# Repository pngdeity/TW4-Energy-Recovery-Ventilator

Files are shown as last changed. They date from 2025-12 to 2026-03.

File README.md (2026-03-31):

<p align="center">
  OpenERV Logo
</p>

# OpenERV TW4 and WM12






OpenERV is a 87%+ efficiency DIY **Energy Recovery Ventilator (ERV)** system designed to provide fresh outdoor air while recovering heat and moisture from the exhaust stream. This repository contains the complete firmware, mechanical designs, and documentation for the **TW4** (Through-Wall) and **WM12** (Window-Mounted) models.

## Key Features
- **High Efficiency**: 87%+ heat recovery efficiency at 60 CFM.
- **Precision Control**: Integrated PID loops for automated pressure regulation using Sensirion SDP810 sensors.
- **IoT Enabled**: Built-in WiFi and MQTT support for remote monitoring and automation.

- **UDP Synchronization**: Leader/Follower UDP synchronization for multi-module installations.

## Project Structure

- **`firmware/`**: MicroPython source code for the Raspberry Pi Pico W.
  - `common/`: Modular core engine, drivers, and safety state machine.
  - `tw4/`, `wm12/`: Model-specific entry points.
- **`design/`**: Mechanical and electrical design assets.
  - `parts/`: STL and STEP files for all printable components.
  - `schematics/`: PCB designs and wiring diagrams.
- **`docs/`**: Manuals, assembly guides, and technical specifications.
- **`research/`**: Historical CAD iterations and experimental validation data.
- **`scripts/`**: Automation utilities for manufacturing analysis and BOM extraction.

## Installation (Flashable Firmware)

The fastest way to deploy OpenERV is to use our pre-compiled firmware images:

1. Download the latest **`.uf2`** binary for your model from the [GitHub Releases](https://github.com/pngdeity/TW4-Energy-Recovery-Ventilator/releases) page.
2. Hold the **BOOTSEL** button on your Raspberry Pi Pico W and connect it to your computer via USB.
3. Drag and drop the `.uf2` file into the `RPI-RP2` drive. The unit will automatically reboot into the OpenERV engine.

## Configuration

After flashing, you must configure your local environment:
1. Locate the relevant template in `firmware/config_templates/`.
2. Copy it to the root of your Pico's filesystem as `persistent_vars.json`.
3. Edit the file to include your WiFi credentials, model ID, and optional Adafruit IO keys.

## Documentation & Roadmap

Manuals and assembly instructions:
- [DIY Manufacturing Guide](./docs/Document%20to%20aid%20DIY%20manufacturing%20of%20the%20OpenERV%20TW4%20and%20WM12.md)
- [TW4 Manual](./docs/TW4%20manual%20-%20OpenERV.md)
- [WM12 Manual](./docs/OpenERV%20WM12%20manual.md)
- [v1.0 Roadmap](./ROADMAP.md)

## Original Project & Attribution

This project is a formalized fork of the OpenERV system originally developed by **Anthony Douglas**.
- **Original Website**: [openerv.ca](https://www.openerv.ca)
- **Licensing**: This project is licensed under **CC BY-NC-SA 4.0**. See [LICENSE](LICENSE) for details.

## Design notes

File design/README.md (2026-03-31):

# OpenERV Hardware Design

This directory contains all the mechanical and electrical design files for the OpenERV TW4 and WM12 units.

## Directory Structure

- **`parts/`**: 3D design files (STL for printing, STEP for CAD modeling).
  - **`common/`**: Parts shared by both TW4 and WM12 models (covers, plates, noise splitters).
  - **`tw4/`**: Parts unique to the TW4 model (e.g., flow straighteners).
  - **`wm12/`**: Parts unique to the WM12 model (e.g., window adapters).
- **`schematics/`**: Electrical schematics, PCB layouts, and sensor pinouts.
  - **`source/`**: Raw EasyEDA JSON source files.

## Bill of Materials (BOM)

Bills of Materials are provided in the [OSHWA](https://www.oshwa.org/) recommended CSV format:
- **`BOM_TW4.csv`**: Parts list for a single TW4 module.
- **`BOM_WM12.csv`**: Parts list for a complete WM12 window-mounted unit (includes 2x modules and adapter hardware).

These files include component names, quantities, technical descriptions, and suggested sourcing information (e.g., LCSC/DigiKey part numbers where applicable).

## Manufacturing

### Automated Manufacturing Reports
This repository uses **PrusaSlicer CLI** in a GitHub Action to automatically audit every 3D model change. On every push to the `main` branch, a report is generated containing:
- **Print Time Estimates**: Calculated using the project's manufacturing profile.
- **Material Usage**: Estimated weight in grams.
- **Physical Dimensions**: Precise bounding box measurements.

The latest report can be found in the `design/` directory as **`MANUFACTURING_REPORT.csv`**.

### 3D Printing Specifications
Material and slicer requirements are provided in **`print_specs.json`** files within each sub-directory. These files use a schema to define:
- **Recommended Materials**: (e.g., MPLA for high thermal resistance).
- **Infill Settings**: Specific densities and patterns (e.g., 100% infill for mechanical regions).
- **Layer Details**: Wall counts and layer heights required for structural integrity.

For detailed assembly and manufacturing instructions, please refer to the documentation in the root `docs/` directory:
- [DIY Manufacturing Guide](../docs/Document%20to%20aid%20DIY%20manufacturing%20of%20the%20OpenERV%20TW4%20and%20WM12.md)
- [TW4 Manual](../docs/TW4%20manual%20-%20OpenERV.md)
- [WM12 Manual](../docs/OpenERV%20WM12%20manual.md)

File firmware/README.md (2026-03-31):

# OpenERV Firmware

This directory contains the MicroPython firmware for the OpenERV TW4 and WM12 units. The firmware has been refactored into a modular, object-oriented architecture to maximize code reuse and reliability across different hardware models.

## Software Architecture

The firmware follows a **Core-Wrapper** pattern. The heavy lifting is handled by a shared core library, while model-specific directories contain minimal configuration and entry logic.

### 1. Model Entry Points (`/tw4` and `/wm12`)
These directories contain the `main.py` files that serve as the entry point for the Raspberry Pi Pico W.
- **`main.py`**: A "thin wrapper" that defines model-specific constants (like pressure gains and I/O pins) and instantiates the `OpenERVCore`.
- **`persistent_vars.json`**: (User-created) Local configuration file containing WiFi credentials and device-specific settings.

### 2. Common Library (`/common`)
This directory contains the engine of the project. By centralizing this logic, we ensure that improvements to the PID loop or networking stability benefit all models simultaneously.
- **`core_logic.py`**: Contains the `OpenERVCore` class. This is the main state machine that orchestrates sensor reading, PID calculation, fan control, and network synchronization (Leader/Follower).
- **`sdp810.py`**: A class-based driver for the Sensirion SDP810 differential pressure sensor with built-in error handling.
- **`fan_manager.py`**: Manages fan pairs and implements the coordinated ramp-down logic required for efficient energy recovery.
- **`network_manager.py`**: Handles WiFi station connections and Access Point (AP) mode.
- **`simple_pid/`, `umqtt/`, `uping.py`**: Standardized third-party libraries for PID control, MQTT communication, and network diagnostics.

### 3. Configuration Templates (`/config_templates`)
Contains example `persistent_vars.json` files for each model. To configure a new device:
1. Copy the relevant template to the root of your Pico.
2. Rename it to `persistent_vars.json`.
3. Update it with your WiFi and Adafruit IO credentials.

### 4. Experimental Scripts (`/experimental`)
Diagnostic and characterization tools used for hardware validation and efficiency measurements. See the [Experimental README](./experimental/README.md) (if available) for more details.

## Control Logic Flow

1. **Initialization**: The device loads configuration, initializes the I2C sensor, and sets up PWM for the fans.
2. **Connectivity**: The unit attempts to connect to WiFi. If configured as a **Leader**, it optionally connects to MQTT for telemetry. If a connection fails, it may fall back to **Access Point** mode.
3. **Synchronization**:
   - **Leaders** broadcast their internal clock and power settings via UDP.
   - **Followers** listen for these UDP packets to synchronize their cycles with the leader.
4. **The Loop**:
   - **Ingress Phase**: The unit runs a PID loop to maintain the target pressure for incoming air.
   - **Egress Phase**: The unit reverses the cycle, running a PID loop for outgoing air.
   - **Ramping**: The `FanManager` ensures that fans don't snap between speeds, protecting the hardware and reducing noise.

## Development Guidelines

- **Stay Modular**: Do not add hardware-specific logic to `core_logic.py`. Instead, add a configuration parameter to the `OpenERVCore` constructor.
- **Error Resilience**: Always use `try/except` blocks when communicating with I2C sensors or network sockets to prevent the device from hanging.
- **WDT**: The Watchdog Timer is enabled by default. Ensure that any long-running operations (like network handshakes) "feed" the watchdog to avoid unintended resets.

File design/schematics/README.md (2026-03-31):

# OpenERV Schematics and PCB Design

This directory contains the electrical design files for the OpenERV systems.

## Contents

- **`pcb_schematic_v2.png`**: Current schematic for the TW4/WM12 main board.
- **`pcb_schematic_v1.pdf`**: Previous version or alternative view of the schematic.
- **`sensor_sdp810_pinout.png`**: Pinout reference for the Sensirion SDP810 differential pressure sensor.
- **`source/`**: Contains the raw EDA source files.
  - `1-Schematic_TW4 Main board2.json`: EasyEDA schematic source.
  - `1-PCB_PCB_TW4 Main board2.json`: EasyEDA PCB layout source.

## Using the Source Files

The source files in the `source/` directory are in **EasyEDA (Standard Edition)** format. To view or modify them:

1. Go to [EasyEDA](https://easyeda.com/).
2. Log in and open the Editor.
3. Use **File -> Open -> EasyEDA...** and upload the `.json` files.
4. You can then export Gerbers, BOMs, and Pick-and-Place files directly from the editor for manufacturing.

## Component Sourcing

Key components like the Raspberry Pi Pico W and the SDP810 sensor should be sourced from reputable suppliers (e.g., DigiKey, Mouser) to ensure reliability. Refer to the project manuals in the `docs/` folder for detailed Bills of Materials (BOM).

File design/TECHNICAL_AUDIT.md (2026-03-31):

# Technical Audit: OpenERV Design Assets

This document details the findings of a technical audit performed on the mechanical and electrical design files within the `design/` directory.

## 1. Summary of STL Analysis

All STL files were analyzed using `admesh` for geometric integrity and physical dimensions.

| Part Name | Status | Parts | Volume (mm³) | Bounding Box (mm) | Issues Found |
| :--- | :--- | :--- | :--- | :--- | :--- |
| `combi_hood.stl` | Healthy | 1 | 158,890 | 166.6 x 175.6 x 151.6 | None |
| `fiberglass_grid.stl` | Healthy | 1 | 11,696 | 195.6 x 166.6 x 3.0 | None |
| `filter_clamp.stl` | Healthy | 1 | 17,450 | 208.5 x 101.5 x 33.5 | None |
| `filter_seat.stl` | Healthy | 1 | 80,682 | 214.9 x 182.0 x 20.0 | None |
| `hat_seat.stl` | Healthy | 1 | 34,282 | 173.0 x 177.3 x 12.0 | None |
| `indoor_plate.stl` | Healthy | 1 | 161,253 | 187.7 x 219.1 x 14.5 | Tight fit for 220mm beds. |
| `interior_cover.stl` | Healthy (Fixed) | 1 | 180,584 | 200.0 x 220.8 x 75.1 | Normals repaired. |
| `noise_splitter.stl` | Healthy | 2 | 669,905 | 184.0 x 166.9 x 218.8 | Multi-body part (intentional?). |
| `outdoor_cover.stl` | Healthy (Fixed) | 1 | 394,679 | 223.0 x 230.8 x 146.8 | Normals repaired. Requires 250mm+ bed. |
| `outdoor_plate.stl` | Healthy (Fixed) | 1 | 462,341 | 215.0 x 220.0 x 18.0 | Normals repaired. |
| `pipe_extension.stl` | Healthy | 1 | 31,915 | 111.6 x 111.6 x 33.0 | None |
| `pot_mount.stl` | Healthy | 1 | 3,914 | 23.0 x 23.0 x 29.2 | None |
| `pot.stl` | Healthy | 1 | 2,712 | 24.0 x 16.4 x 23.8 | None |
| `regen.stl` | Healthy | 1 | 3,096,175| 148.5 x 148.8 x 180.0 | High volume print. |
| `std_filter_plate.stl`| Healthy | 1 | 66,482 | 209.3 x 182.0 x 20.0 | None |
| `clamp_v2.stl` | Healthy | 1 | 69,363 | 159.0 x 159.0 x 10.0 | None |
| `flow_straightener.stl`| Healthy | 1 | 59,999 | 120.4 x 120.4 x 19.0 | None |

## 2. Integrity Issues & Proposed Changes

### A. Surface Normal Correction
Several files exhibit "Flipped Normals" or "Backwards Edges." While most modern slicers (Cura, PrusaSlicer) can auto-repair these on import, they can cause issues with professional CNC or injection molding software.
- **Proposed Change**: Re-export `interior_cover.stl`, `outdoor_cover.stl`, and `outdoor_plate.stl` from the source CAD with unified surface normals to ensure manifold integrity.

### B. Printer Bed Compatibility
- **`outdoor_cover.stl`**: At 223mm x 230mm, this file exceeds the standard 220mm (Ender 3 class) print bed.
- **`interior_cover.stl`**: At 220.8mm, it may fail on printers with strict software endstops.
- **Proposed Change**: Consider a minor design revision to the `outdoor_cover` to bring the largest dimension under 215mm, or explicitly mark this part as "Large Format Only" in the filename.

### C. Multi-Body Parts
- **`noise_splitter.stl`**: Contains 2 distinct shells. This can sometimes cause slicers to treat them as overlapping solids, leading to over-extrusion at the boundary.
- **Proposed Change**: Merge shells into a single manifold boolean object before re-exporting.

## 3. STEP File Verification
The STEP files (`rev_11_tw4_v35.step`, etc.) are in standard ISO-10303-21 format.
- **Observation**: The filenames are inconsistent with the STL counterparts.
- **Proposed Change**: Rename STEP files to match the part names used in the `stls/` directory for better cross-referencing.

## 4. Electrical Schematics
The EasyEDA source files are current but use proprietary JSON schema.
- **Proposed Change**: In the next design cycle, include an **IPC-2581** or **ODB++** export in the `schematics/source` directory to provide a software-agnostic manufacturing exchange format.

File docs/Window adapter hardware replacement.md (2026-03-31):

# WM12 Technical Specification: Hardware Replacement

This document lists the standard hardware components required for the WM12 window adapter.

## Mechanical Components

### Clamps
- **Type**: Key-type hose clamps.
- **Diameter**: 6 inches (approx. 152 mm).

### Fasteners
- **Screws**: 3/4 inch, Number 2 Robertson (Square Drive, Green).

### Brackets
- **Type**: Standard 1.5-inch metal brackets (generic hardware store stock).

### Structural Timber
- **Dimension**: 2x2 nominal (actual approx. 1.5" x 1.5" or 38mm x 38mm).

### Sealing Medium
- **Material**: Polypropylene (PP) foam plate.
- **Source**: Commonly used as industrial packaging material.

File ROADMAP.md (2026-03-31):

# OpenERV v1.0 Roadmap

This roadmap outlines the critical tasks and features required to reach a Version 1.0 milestone.

## 1. Hardware Completeness (Mechanical)
- [ ] **Release Mandrel CAD**: Publish the design files for the Heat Exchanger Hat forming mandrel.
- [ ] **Validated Assemblies**: Confirm that all renamed STEP files correctly resolve in standard CAD software (KiCad/FreeCAD).
- [ ] **Assembly Video/Guide**: Create a visual assembly guide to supplement the Markdown documentation.

## 2. Firmware Functionality & Safety
- [ ] **Automated Defrost Cycle**: Implement logic to detect frost accumulation (via pressure drop) and trigger a temporary exhaust-only purge.
- [ ] **PID Auto-Tuning**: Provide model-specific PID constants for TW4 and WM12 based on physical volume characterization.
- [ ] **Watchdog Hardening**: Refine WDT timeouts for critical networking handshakes to prevent false-positive reboots.

## 3. User Experience (UX)
- [ ] **IoT Provisioning (V1.0)**: Mature the Captive Portal to include a WiFi scanner (showing available SSIDs).
- [ ] **Persistent Variables Validation**: Add schema validation for `persistent_vars.json` to prevent boot loops from malformed JSON.
- [ ] **Home Assistant Discovery**: Implement MQTT discovery for smart home integration.

## 4. Electronics & Manufacturing
- [ ] **KiCad Migration**: Transition the main PCB from EasyEDA to KiCad for full open-source toolchain support.
- [ ] **Production Gerbers**: Include a verified set of Gerber files in each release.
- [ ] BOM Finalization: Finalize LCSC part mappings for all components to support automated PCBA services.

## 5. Community & Standards
- [ ] **OKH Certification**: Submit the project for official Open Source Hardware Association (OSHWA) certification.
- [ ] **Contributor Guide**: Expand `CONTRIBUTING.md` with technical environment setup instructions.

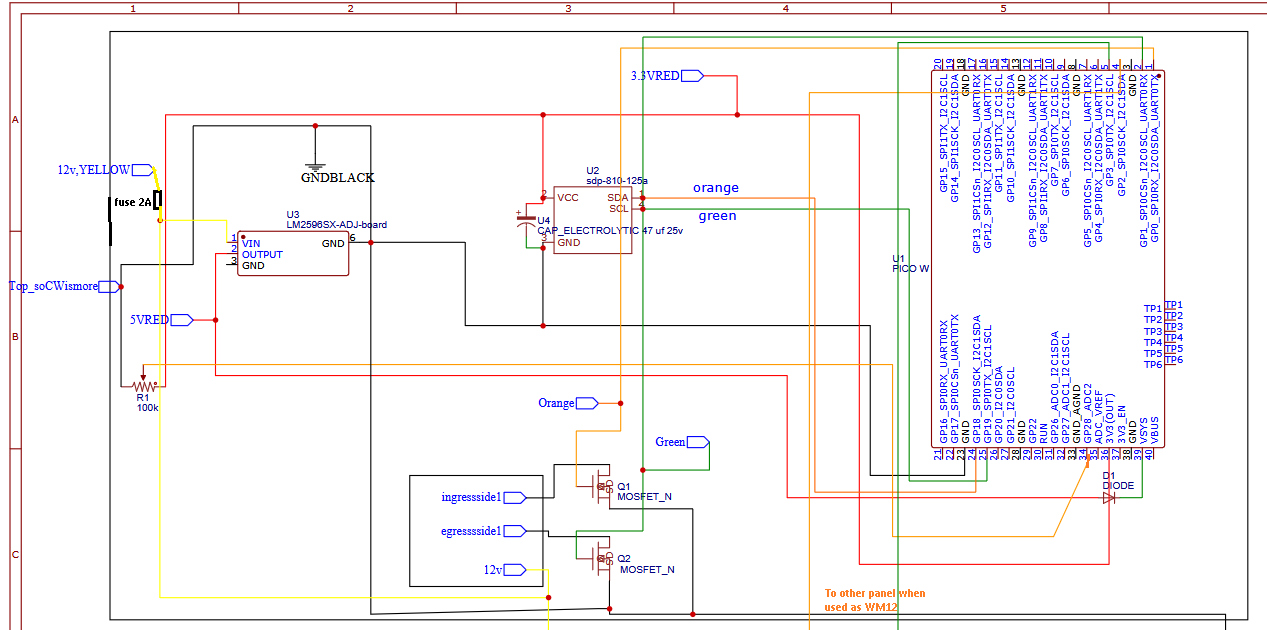
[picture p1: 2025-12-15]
design/schematics/pcb_schematic_v2.png

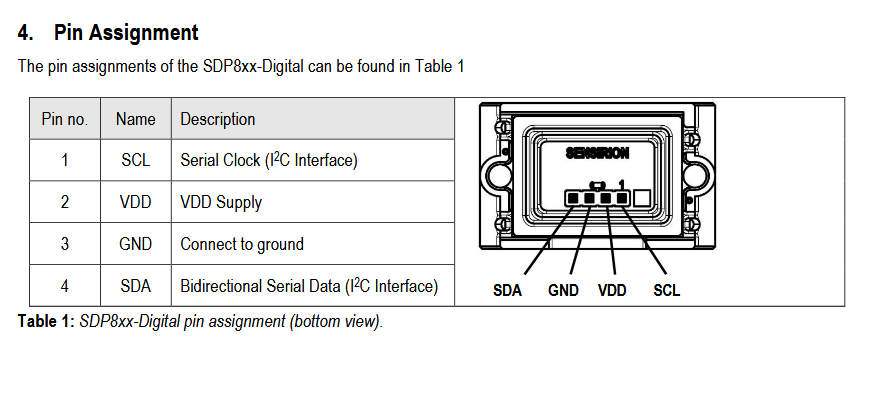
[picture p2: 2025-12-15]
design/schematics/sensor_sdp810_pinout.png

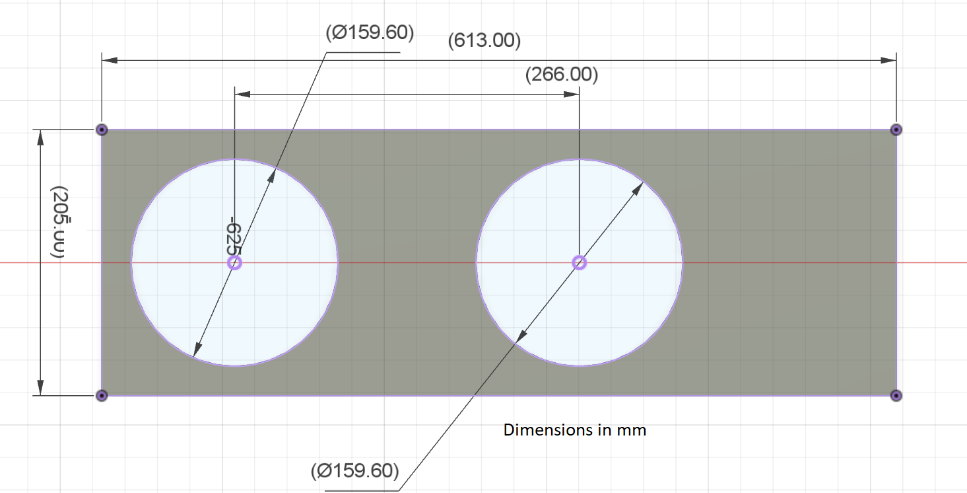
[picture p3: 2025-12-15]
wm12/WM12/v2foamplatewindowadapterforwm12.png

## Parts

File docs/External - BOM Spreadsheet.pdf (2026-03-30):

Input cells are in blue, the most important output cells are in red, you need to save a copy before you can edit. The methodology is similar to that used here https://www.caee.utexas.edu/prof/Novoselac/classes/ARE389H/Handouts/Old_Projects/ERV%20Report.pdf, which assumes a thermal wheel. The physics for the ductless (both regenerative) type are mostly the same, but not for the recouperative, they have issues at low temperatures due to frost. units | All dollars are Canadian dollars units Flow rate, CFM: | 15 CFM | Actual amount of fresh air, remember this is usually for a *pair* of units cost of electricity, dollars per kWh | 0.16 kWh | factoring in lifespan of unit to running cost. This means the average time before the initial cost of the unit has been expended upon maintenance. For conventional units, this will depend on if you can get replacement parts, or if the whole thing becomes trash when e.g. the fan wears out.
flow rate, liters per second: | 7.075 liters per second | cost per cubic meter of natural gas, dollars | 1.3 CAD/m^3 | notes
electrical power consumed by device when at that flow, Watts. | 7 | Watts | cost per kWh of natural gas derived heat energy | 0.1336211327 CAD/kWh | lifespan | 40 years Months on per year | 8 | Months | This figure is not strictly necessary, the calculations could be done with the heating degree days per year, however it is used to calculate some intermediate figures. assumed purchase price for a pair of modules | 1000 CAD | Initial cost, including tax and shipping etc. for heat recovery aspect | 1110 CAD
electrical Energy consumed, per year, kWh: | 40.88 kWh | tax/duty | 15 | Percent | Spare parts and electricity per year etc along the way | 16.5408 CAD/year
liters of air per day provided, fresh air | 611280 liters per day | shipping | 60 | CAD | Gross cost of ownership/operation (no interest, comparative value only) per year | 44.2908 CAD/year energy to heat the air for the year without any heat recovery, kWh, sensible only | 953.5968 kWh | installation | 0 | CAD | Gross return on investment (assuming natural gas heat) | 170.7848207 CAD/year efficiency of heat recovery, sensible | 0.85 Unitless ratio | rebates/tax credits etc., some governments give these | 0 CAD | Net return on investment, per year | 126.4940207 CAD/year heat energy directly saved by device, sensible, per year | 810.55728 kWh | value of the fan, without heat recovery (you need a fan anyway most of the time, reduce this figure for retrofit if you are replacing an existing but functional fresh air supply system with no heat recovery) 100 CAD | Net Ownership/operating cost over total lifespan | 1771.632 CAD
heat capacity of air, volumetric, joules per degree per liter | 1.2 J/DegC-Liter | Total cost including fan aspect | 1210 | CAD Marginal cost of heat recovery aspect of the machine (the house needs a fan anyway) | 1110
heating-degree-days per year: | 4,680 degree-days per year https://portfoliomanager.energystar.gov/pm/degreeDaysCalculator , https://www.degreedays.net System running cost, per year, including electricity | 16.5408 CAD | Total cost of energy saved over life span,natural gas: | 6831.39283 CAD Maintenance cost, per year, worn parts etc. (estimate, includes labor) | 10 dollars | gross dollars saved on heating, assuming natural gas heat | 170.7848207 CAD | Total cost of energy saved over life span, electric: | 8180.014873 CAD | energy saved, kWh 51125.09295
latent heat recovery efficiency, seasonal average (Toronto) | 0.8 unitless ratio | Change this if using coated vs uncoated exchagners! Makes a big diff. gross dollars saved on heating, assuming electric heat | 204.5003718 CAD | ratio of ownership per year cost to energy saved per year, natural gas | 0.259336865 Ratio, lower is better kWh per dollar expended 28.8576256 Fraction of total heat that is is expected to be present as latent heat | 0.38
0.4 is about right for toronto, I checked the weather data | ratio of total ownership cost to energy savings, electric resistance heat | 0.2165805353 Ratio, lower is better
total yearly heat needed without ERV | 1538.059355 Total cubic meters of air | 223117.2
energy per cubic meter | 0.006893504198 kWh
latent heat present in air | 584.4625548
latent heat saved by device, approximate | 467.5700439 kWh | assuming seasonally, about 1/6 of total energy is latent (20%, 1/5 of sensible heat appears, in addition, as latent heat) | total savings over lifespan | 6408.382873 Total heat saved by device | 1278.127324 kWh | These figures don't include running costs and lifespan, use cyan colored ones for more accuracy. | Tw4 is about 21.64 times better return on investment ratio
net averager efficiency | 0.831 Total hours of operation | 5856 | Total saved per year, natural gas heat plus savings on electric in summer on AC | 157.1542569 | CAD | with interest on savings watts thermal energy recovered, average, during operation | 218.2594474 | savings per month | 10.5411684 Embodied carbon for energy recovery ventilator: | months elapsed | 480
plastic, pla | 1.4 kg of CO2 | payoff period, years, naive (no interest), gas heat | 7.063123977 | CAD | interest rate per year | 1.03 motors | 2 kg of CO2 | Total saved per year, electric heat, not including summer | 187.9595718 | CAD | interest rate per month | 0.002466269772
electronics | 2 kg of CO2 | Total $ saved per year, electric heat plus savings on electric in summer on AC | 190.869808 | CAD | final value | $9,668.25
printing | 1 kg of CO2 | payoff period for electric heat, years, naive (no interest) | 5.815482353 | CAD
unit's embodied carbon | 6.4 kg of CO2 | Ratio of rate of return on investment, ERV to PV installation assuming natural gas heating | 1.958235292 | CAD | cost of a house | $400,000 Kg of carbon dioxide per kWh of natural gas combusted: | 0.286 Kg of CO2 per kWh of heat from natural gas | Ratio of rate of return on investment, ERV to PV installation, electric heat | 2.378351065 CAD | 41.37251896 Energy yield from one cubic meter of natural gas, kWh, with furnace at 90% efficiency: | 9.729 kWh | Carbon cost figures (doesn't factor in cooling savings) Manufacturing kg of cabon dioxide released per kWh of electricity consumed (kg carbon per kWh in the area the manufacturing is done) 0.04 | kg/kWh | cabon dioxide emission prevented per year by heating of air saved: | 231.8193821 | kg CO2 Running (kg of cabon dioxide released per kWh of electricty consumed) | 0.14 | kg/kWh | CO2 emitted by electrical consumption of device | 5.7232 | kg CO2
net carbon savings per year, kg CO2 | 226.0961821 kg CO2 Comparison with a photovoltaic array, installed | Carbon payback period of device, naive (no interest), years | 0.02830653725 | Ratio Embodied energy, kg of carbon dioxide per kW of installed panel (this is the amount which gives 1 kW of electrical energy at full sun, which is about 1.1 kw per square meter of sunlight. So several square meters of panel) 2,560 kg CO2 | Carbon payback period of an equivalent PV panel, years, if the energy from the panel is used to diplace natural gas heating energy 7.474064699 | Ratio Net kWh that 1 kW of installed panel gives, per year, in your area, kWh | 1166 kWh | https://www.energyhub.org/ontario/ Ratio of carbon payback periods: | 264.0402333 Ratio Thus, the OpenERV, at the flow rate indicated, gives the equivalent energy yield of how many kW of panel? Total energy saved, minus electrical consumption of the unit. 0.6601005832 "kW" of panel | Kg of CO2 saved per year per dollar capital investment, open erv | 0.2036902541 (kg/year)/CAD
Dollar cost of the pv system, per kW actual installed capacity (includes inverter, installation etc.) | 2200 CAD | Kg CO2 saved per year per dollar, photovoltaic | 0.0742 (kg/year)/CAD
Financial value of the OpenERV, at the same $/KWh that a photovoltaic system provides (electric heat) : 1452.221283 CAD | Ratio of Kg CO2 saved per year per dollar(ERV/PV): | 2.745151673 Ratio Dollar value of OpenERV, in equivalent PV system, natural gas heat | 2013.971943 CAD
Embodied energy of a photovoltaic array that gives the same amount of energy: | 1689.857493 kg of CO2 Carbon emission savings per year for 1kW PV array, kg of carbon | 163.24 kg CO2 PV installation running cost per kWh capacity, 1.25 percent of capital cost per year | 27.5 | https://www.powerfromsunlight.com/operational-costs-solar-panel-system/ Dollars saved per year for a 1kW PV array | 159.06 CAD
Payoff period for a 1kW PV array, naive, no interest | 13.83125864 years Payoff period, with interest | Systems of equal cost, natural gas heating

photovoltaic system ERV Units capital cost (let's assume they are the same, and scale system size) 1110 1110 CAD Interest rate, per year, percent 0.5045454545 7 7 Percent per year kW rating of PV system that costs that much

payoff rate, dollars per year | 50.96044754 80.253 40 Total heat energy saved over X years: | 157.1542569 Period to pay off, years. 10.08069767 Years to accrue energy and co2 savings (X) 9043.847283 kg monetary savings (natural gas heat maintenance and electricity cost factored in) 6286.170276 CAD 7634.792319 CAD 51125.09295 kWh Total CO2 savings over X years 2173.641174 natural gas heating assumed monetary savings (electric heat maintenance and electricity cost factored in) electric heat Equivalent value of ERV unit, cost of PV array that gives the same return
cooling physics and financial calculations | units
cooling degree days in your area | 260 degree-days | ottawa is about 260 , pheonix arazona is about 2729 https://portfoliomanager.energystar.gov/pm/degreeDaysCalculator
liters per second total watt hours of energy that could be captured at 100% efficiency latent heat energy latent efficiency sensible heat recovered, per season latent heat recovered, per season cost of electricity for heat pump without energy recovery | 7.075 L/s watts per degree (watt-days per degree days) 54.566928 kWh Coefficient of performance for heat pump 7946.64 Wh Total heat energy recovered per season 3 Electricity saved | This is a crude estimate, climate data with humidity data is needed to know more precisely. sensible efficiency

8.49 W/deg-C 52977.6 Wh 15893.28 Wh 0.88 unitless ratio 0.5 unitless ratio 46620.288 Wh 18.188976 kWh 2.91023616

| | units
Flow | 60 | cfm
efficiency, sensible | 0.7 | ratio
latent efficiency | 0.6 | ratio
electricity use | 60 | watts
capital cost | 1250 | $
expected lifespan | 8 | years
maintenance cost/yr during lifespan 0 | | $/yr
shipping | 100 | $

| | units
Flow | 85 | cfm
efficiency, sensible | 0.6 | ratio
latent efficiency | 0.6 | ratio
electricity use | 68 | watts
capital cost | 1207 | $
expected lifespan | 15 | years
maintenance cost/yr during lifespan 0 | | $/yr
shipping | 100 | $

notes: This one is recuperative, which has frost up problems in colder weather.

| | units
Flow | 30 | cfm
efficiency, sensible | 0.5 | ratio
latent efficiency | 0.2 | ratio
electricity use | 7 | watts
capital cost | 1250 | $
expected lifespan | 7 | years
maintenance cost/yr during lifespan 0 | | $/yr
shipping | 100 | $

| | units
Flow | 60 | cfm
efficiency, sensible | 0.85 | ratio
latent efficiency | 0.5 | ratio
electricity use | 13 | watts
capital cost | 650 | $
expected lifespan | 40 | years
maintenance cost/yr during lifespan 10 | | $/yr
shipping | 100 | $

parameter | value | units
Cost of heat, electric resistance | 0.165 | $/kWh
cost of heat, natural gas | 0.13 | $/kWh
tax rate on erv purhase | 0.15 | ratio
heating degree days | 4700 | degree-days per year
cooling degree days | 265 | degree-days per year
cost of a fan without erv | 0 | $

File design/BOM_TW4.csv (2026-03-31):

Index | Designator | Quantity | Name | Description | Manufacturer | Part Number | Supplier | Supplier Part Number | Footprint | Notes
1 |  | 8 | Regenerator Slices | Coated or uncoated heat exchanger slices |  |  | OpenERV |  | Custom
2 |  | 1 | Regenerator Tape | High-temp tape (Tuck Tape recommended) |  |  | Local Hardware Store |  | N/A
3 |  | 1 | Indoor Cover | 3D Printed Cover (MPLA/PLA Pro) |  |  | OpenERV |  | Custom | 250x250mm bed required
4 |  | 1 | Fiberglass Grid | 3D Printed Grid |  |  | OpenERV |  | Custom
5 |  | 1 | Potentiometer Mount | 3D Printed Mount |  |  | OpenERV |  | Custom
6 |  | 1 | Indoor Plate | 3D Printed Plate |  |  | OpenERV |  | Custom
7 |  | 1 | Noise Splitter Body | 3D Printed Main Body |  |  | OpenERV |  | Custom
8 |  | 1 | Pipe Extension | 3D Printed Inner Pipe Extension |  |  | OpenERV |  | Custom
9 |  | 1 | Hat Seat | 3D Printed Hat Seat |  |  | OpenERV |  | Custom
10 |  | 1 | Flow Straightener | 3D Printed Flow Straightener |  |  | OpenERV |  | Custom
11 |  | 1 | Fan Retention Clamp | 3D Printed Clamp |  |  | OpenERV |  | Custom
12 |  | 2 | Fan | 12V DC Fan - corners trimmed | NMB Technologies | 11925SE-12R-FT-DW | DigiKey | P12345-ND | 120mm
13 |  | 2 | Washers | 12mm washers for M3 screws |  |  | Local Hardware Store |  | M3
14 |  | 2 | M4 Bolts | 55mm long M4 bolts |  |  | Local Hardware Store |  | M4
15 |  | 2 | M4 Lock Nuts | Lock nuts for splitter clamp |  |  | Local Hardware Store |  | M4
16 |  | 24 | M3 Screws | 12mm long self-tapping SS screws |  |  | Local Hardware Store |  | M3
17 |  | 2 | M3 Screws (Long) | 25mm long self-tapping M3 screws |  |  | Local Hardware Store |  | M3
18 |  | 2 | M2 Screws | 12mm long self-tapping SS screws |  |  | Local Hardware Store |  | M2 | For Pico mounting
19 | U1 | 1 | Microcontroller | Raspberry Pi Pico W | Raspberry Pi | Pico W | DigiKey | 2122-SC0918-ND | Module
20 | U2 | 1 | Pressure Sensor | Differential Pressure Sensor 125Pa | Sensirion | SDP810-125PA | DigiKey | 1649-1063-ND | Module
21 |  | 1 | Acoustic Damping | Acoustic fiberglass or 170 foam earplugs |  |  | Local/Amazon |  | N/A
22 |  | 1 | Voltage Regulator | Adjustable Buck Regulator (1A+ for Servo/Pico) |  |  | Amazon/Generic |  | Module | Set to 5V
23 |  | 1 | Power Supply | 12V 2A DC Power Supply |  |  | Amazon/Generic |  | N/A
24 |  | 4 | Terminal Connectors | 2.54mm 14-position screw terminals |  |  | DigiKey |  | DIP | For Pico
25 | F1 | 1 | Fuse Holder | Standard glass tube fuse holder |  |  | Local/DigiKey |  | N/A
26 | F1 | 1 | Fuse | 2A Fast Blow Fuse |  |  | Local/DigiKey |  | N/A
27 |  | 2 | MOSFET Boards | Low-side MOSFET control boards |  |  | Amazon/Generic |  | Module
28 | R1 | 1 | Potentiometer | 10k Linear Potentiometer with Knob |  |  | Local/DigiKey |  | N/A
29 |  | 2 | Fan Connectors | 3.81mm Pluggable terminal blocks (M/F pairs) |  |  | DigiKey |  | 3.81mm
30 |  | 1 | Pipe | SDR35 PVC Pipe |  |  | Local Hardware Store |  | 4 inch
31 |  | 1 | Window Film | 50-75 micron BOPET (Mylar) film |  |  | Local/Amazon |  | N/A

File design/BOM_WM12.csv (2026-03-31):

Index | Designator | Quantity | Name | Description | Manufacturer | Part Number | Supplier | Supplier Part Number | Footprint | Notes
1 |  | 16 | Regenerator Slices | Coated or uncoated heat exchanger slices |  |  | OpenERV |  | Custom | 8 per module
2 |  | 1 | Regenerator Tape | High-temp tape (Tuck Tape recommended) |  |  | Local Hardware Store |  | N/A
3 |  | 2 | Indoor Cover | 3D Printed Cover (MPLA/PLA Pro) |  |  | OpenERV |  | Custom | 250x250mm bed required
4 |  | 2 | Fiberglass Grid | 3D Printed Grid |  |  | OpenERV |  | Custom
5 |  | 1 | Potentiometer Mount | 3D Printed Mount |  |  | OpenERV |  | Custom | Only 1 needed for control
6 |  | 2 | Indoor Plate | 3D Printed Plate |  |  | OpenERV |  | Custom
7 |  | 2 | Noise Splitter Body | 3D Printed Main Body |  |  | OpenERV |  | Custom
8 |  | 2 | Pipe Extension | 3D Printed Inner Pipe Extension |  |  | OpenERV |  | Custom
9 |  | 2 | Hat Seat | 3D Printed Hat Seat |  |  | OpenERV |  | Custom
10 |  | 2 | Flow Straightener | 3D Printed Flow Straightener |  |  | OpenERV |  | Custom
11 |  | 2 | Fan Retention Clamp | 3D Printed Clamp |  |  | OpenERV |  | Custom
12 |  | 4 | Fan | 12V DC Fan - corners trimmed | NMB Technologies | 11925SE-12R-FT-DW | DigiKey | P12345-ND | 120mm
13 | U1 | 1 | Microcontroller | Raspberry Pi Pico W | Raspberry Pi | Pico W | DigiKey | 2122-SC0918-ND | Module | Single unit controls both modules
14 | U2 | 1 | Pressure Sensor | Differential Pressure Sensor 125Pa | Sensirion | SDP810-125PA | DigiKey | 1649-1063-ND | Module | Only 1 sensor used in WM12
15 |  | 1 | Voltage Regulator | Adjustable Buck Regulator (1A+) |  |  | Amazon/Generic |  | Module | Set to 5V
16 |  | 1 | Power Supply | 12V 2A DC Power Supply |  |  | Amazon/Generic |  | N/A
17 |  | 4 | MOSFET Boards | Low-side MOSFET control boards |  |  | Amazon/Generic |  | Module | 4 total (1 per fan)
18 | R1 | 1 | Potentiometer | 10k Linear Potentiometer with Knob |  |  | Local/DigiKey |  | N/A
19 |  | 1 | Foam Plate | Polypropylene foam packaging material |  |  | Local/Amazon |  | N/A | Window adapter medium
20 |  | 1 | Structural Timber | 2x2 Nominal Timber (8ft length) |  |  | Local Hardware Store |  | N/A | Window frame support
21 |  | 4 | Metal Brackets | 1.5 inch standard metal brackets |  |  | Local Hardware Store |  | N/A
22 |  | 4 | Hose Clamps | 6 inch diameter key-type hose clamps |  |  | Local Hardware Store |  | 6 inch
23 |  | 48 | M3 Screws | 12mm long self-tapping SS screws |  |  | Local Hardware Store |  | M3
24 |  | 1 | Acoustic Damping | Acoustic fiberglass or 340 foam earplugs |  |  | Local/Amazon |  | N/A
25 |  | 2 | Pipe | SDR35 PVC Pipe |  |  | Local Hardware Store |  | 4 inch
26 |  | 1 | Window Film | 50-75 micron BOPET (Mylar) film |  |  | Local/Amazon |  | N/A

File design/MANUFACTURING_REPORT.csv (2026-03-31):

Part | Dimensions (mm) | Volume (mm³) | Est. Weight (g) | Est. Print Time
combi_hood.stl | 166.576431x175.561752x151.575500 | 158890.890625 | 185.08 | 11h 30m 9s
fiberglass_grid.stl | 195.600006x166.600006x3.000000 | 11696.125000 | 14.13 | 1h 12m 26s
filter_clamp.stl | 208.504715x101.458481x33.500000 | 17450.246094 | 19.43 | 2h 28m 4s
filter_seat.stl | 214.902512x182.000000x20.000000 | 80682.328125 | 69.10 | 5h 20m 27s
hat_seat.stl | 172.956009x177.325394x12.000000 | 34282.929688 | 28.82 | 2h 6m 59s
indoor_plate.stl | 187.664001x219.128006x14.500000 | 161252.703125 | 90.17 | 7h 32m 30s
interior_cover.stl | 200.000000x220.828003x75.142090 | 180584.000000 | 204.51 | 20h 28m 36s
noise_splitter.stl | 184.000000x166.916016x218.800002 | 669905.437500 | 514.30 | 1d 13h 51m 5s
outdoor_cover.stl | 223.000000x230.828430x146.839462 | 394680.187500 | 352.31 | 1d 2h 27m 55s
outdoor_plate.stl | 215.000000x220.000000x18.019741 | 462340.968750 | 198.94 | 13h 33m 57s
pipe_extension.stl | 111.599998x111.599998x33.000000 | 31915.765625 | 38.40 | 2h 33m 38s
pot.stl | 24.000002x16.400001x23.750000 | 2712.554688 | 2.28 | 15m 45s
pot_mount.stl | 23.000000x23.000000x29.175003 | 3914.593750 | 4.52 | 27m 21s
regen.stl | 148.453003x148.750488x180.000000 | 3096175.500000 | 906.53 | 1d 15h 9m 50s
standard_filter_adapter_plate.stl | 209.302521x182.000000x20.000000 | 66482.843750 | 56.29 | 4h 30m 5s
clamp_v2.stl | 159.000000x158.982208x10.000002 | 69363.156250 | 40.43 | 2h 59m 50s
flow_straightener_22deg_40mm.stl | 120.400002x120.400002x18.999999 | 59999.375000 | 50.76 | 4h 40m 11s

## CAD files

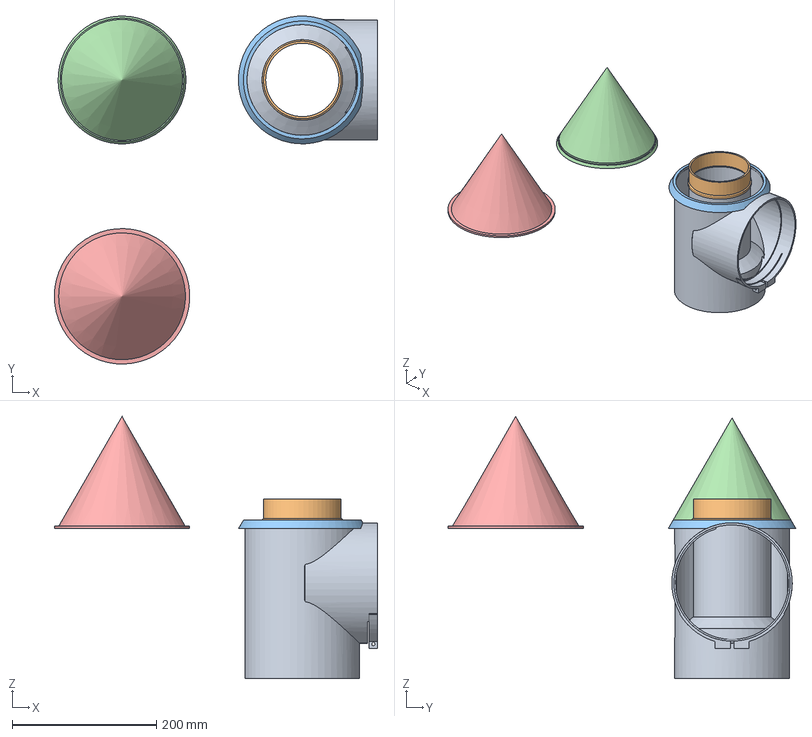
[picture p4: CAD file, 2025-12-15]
design/parts/common/step/noise_splitter.step
448.4 x 482.5 x 363.4 mm

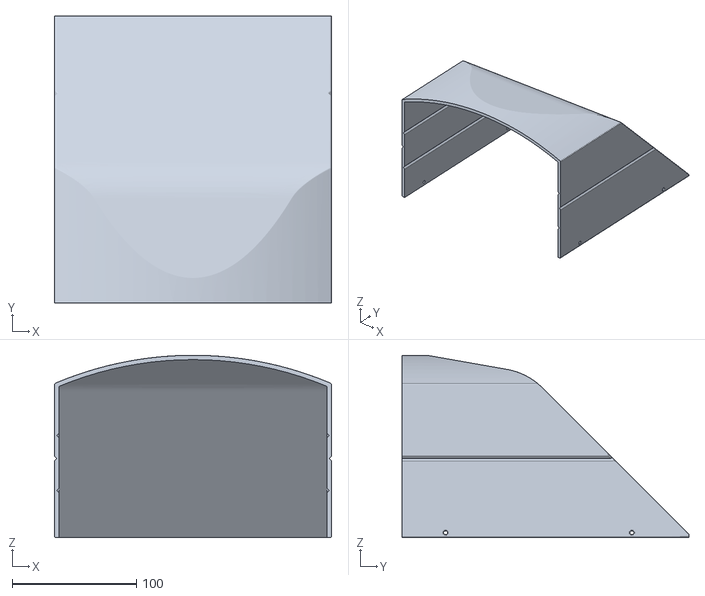
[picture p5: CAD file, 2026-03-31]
design/parts/common/stls/outdoor_cover.stl
223.0 x 230.8 x 146.8

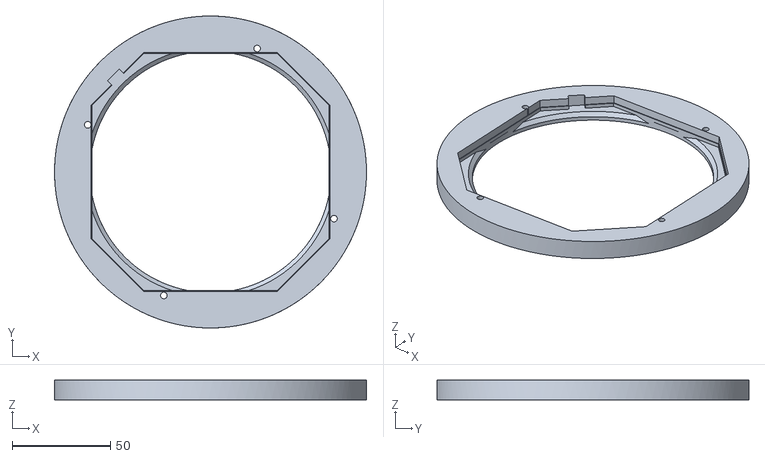
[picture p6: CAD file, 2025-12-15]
design/parts/tw4/stls/clamp_v2.stl
159.0 x 159.0 x 10.0

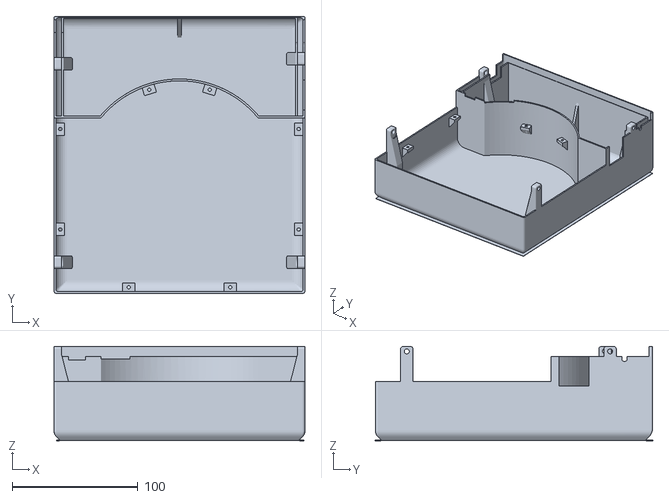
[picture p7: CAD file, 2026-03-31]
design/parts/common/stls/interior_cover.stl
200.0 x 220.8 x 75.1

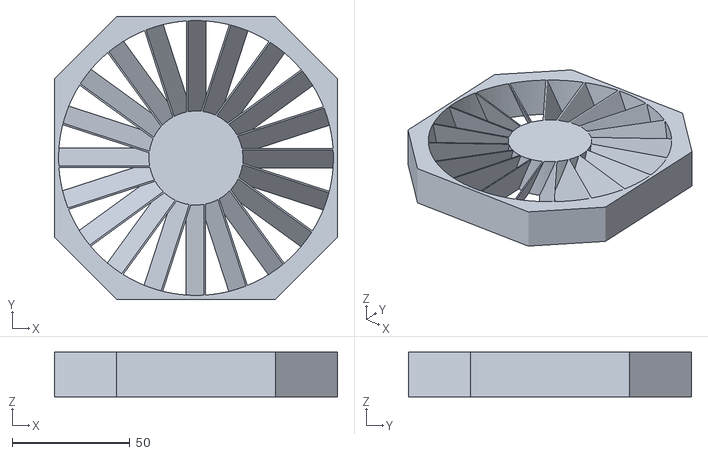
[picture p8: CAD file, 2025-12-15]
design/parts/tw4/stls/flow_straightener_22deg_40mm.stl
120.4 x 120.4 x 19.0

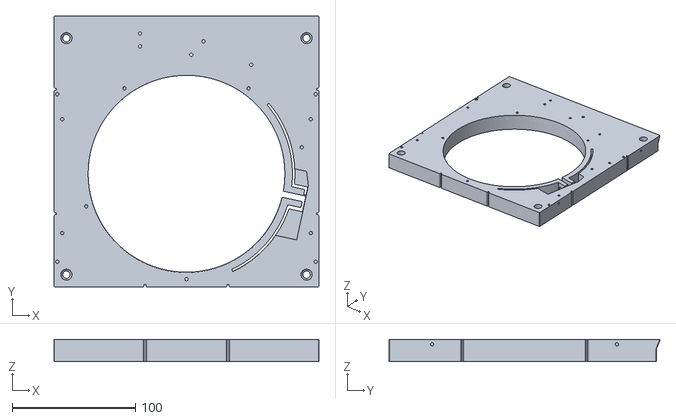
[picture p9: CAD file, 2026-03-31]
design/parts/common/stls/outdoor_plate.stl
215.0 x 220.0 x 18.0

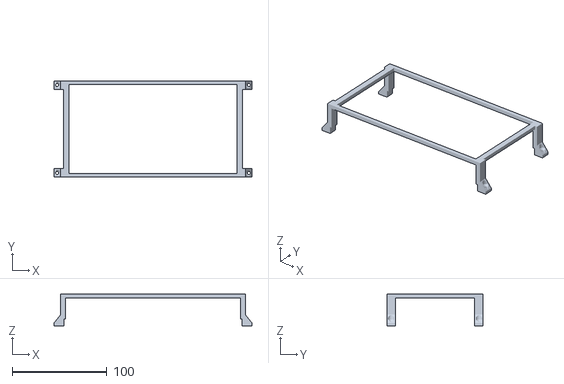
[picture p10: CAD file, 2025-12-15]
design/parts/common/stls/filter_clamp.stl
208.5 x 101.5 x 33.5

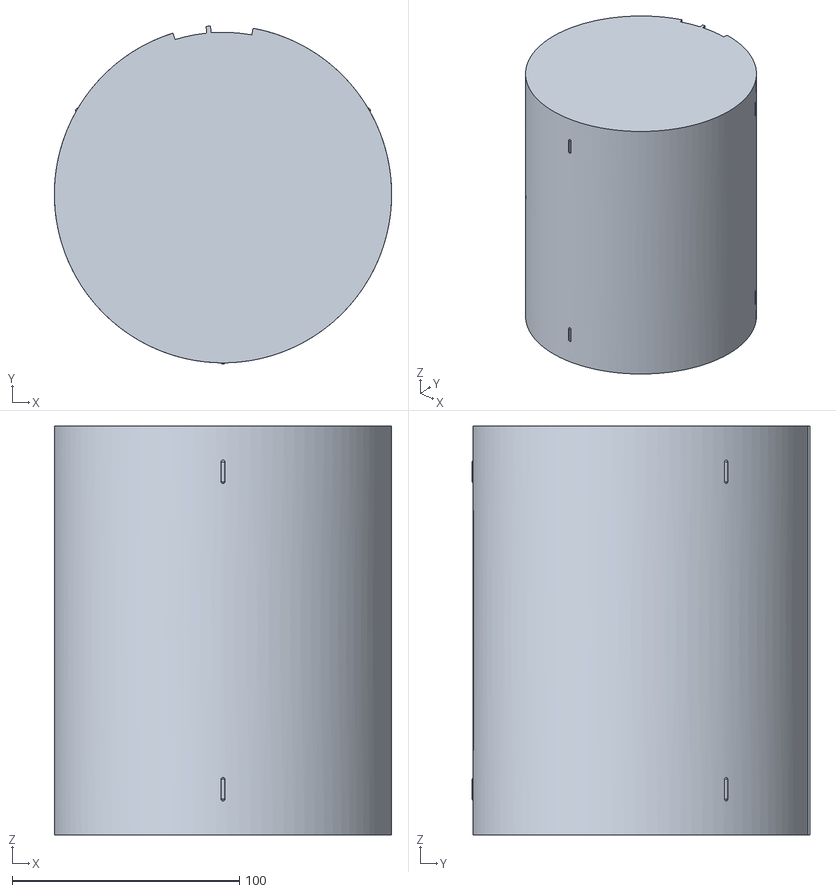
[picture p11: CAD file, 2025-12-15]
design/parts/common/stls/regen.stl
148.5 x 148.8 x 180.0

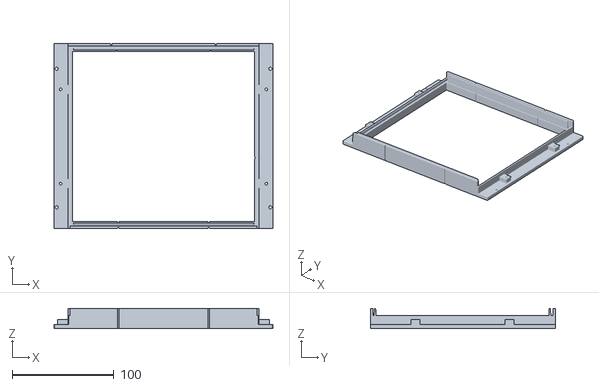
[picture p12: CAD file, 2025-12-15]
design/parts/common/stls/filter_seat.stl
214.9 x 182.0 x 20.0

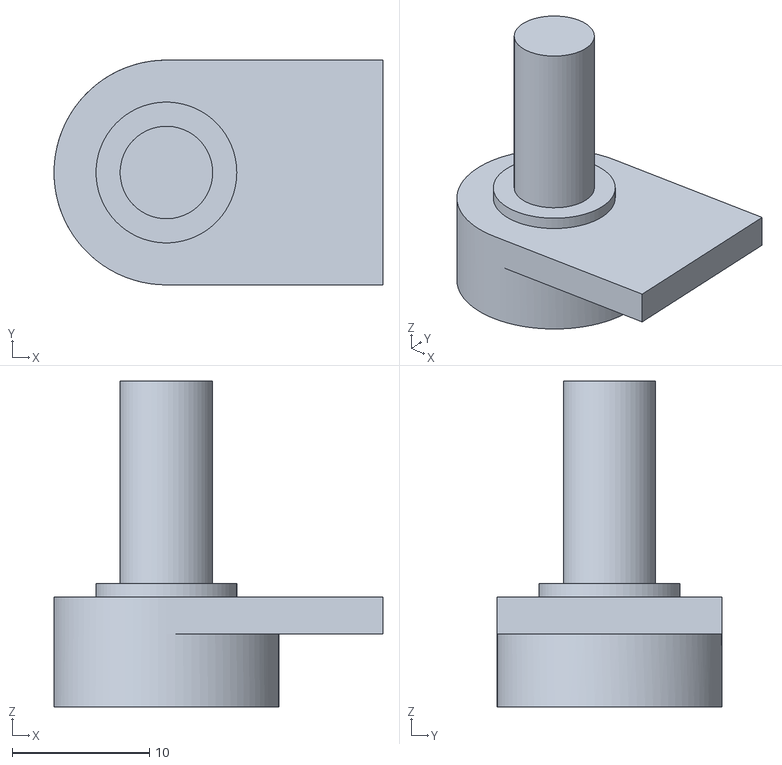
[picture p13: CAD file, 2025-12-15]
design/parts/common/stls/pot.stl
24.0 x 16.4 x 23.8

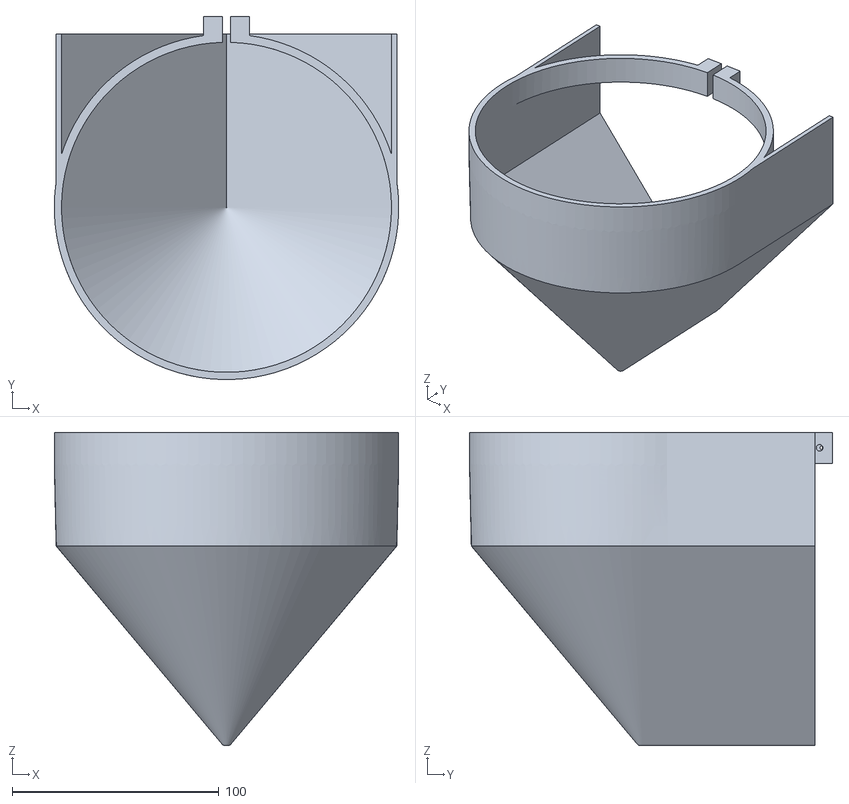
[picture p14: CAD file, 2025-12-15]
design/parts/common/stls/combi_hood.stl
166.6 x 175.6 x 151.6

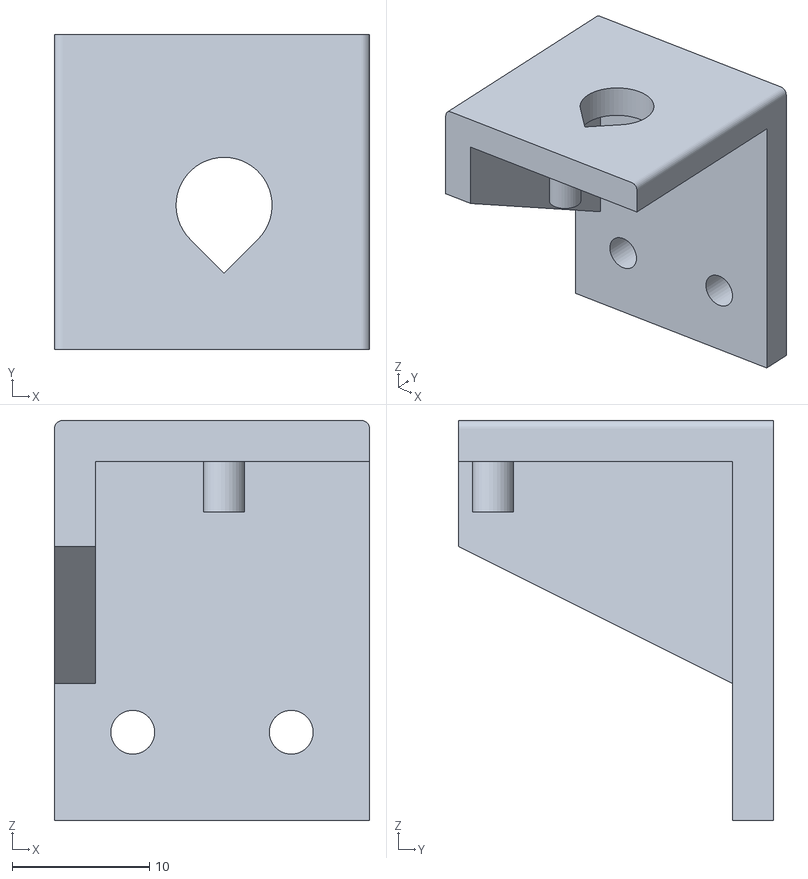
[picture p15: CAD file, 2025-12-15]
design/parts/common/stls/pot_mount.stl
23.0 x 23.0 x 29.2

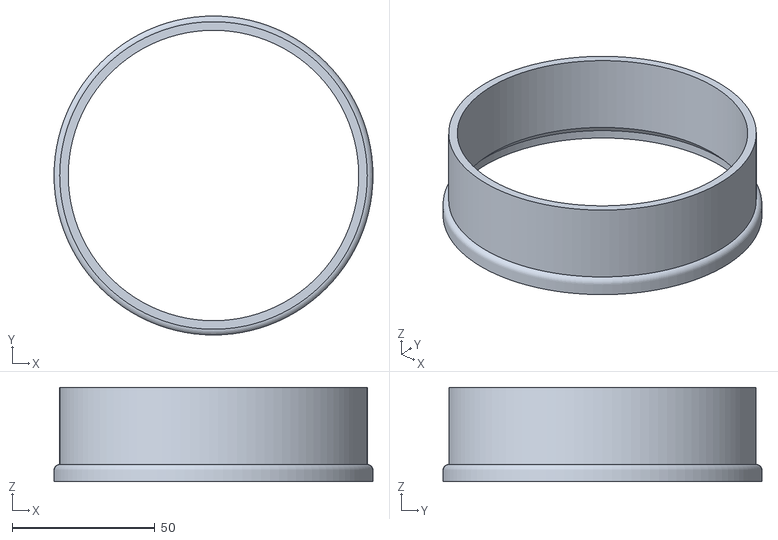
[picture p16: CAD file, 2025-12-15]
design/parts/common/stls/pipe_extension.stl
111.6 x 111.6 x 33.0

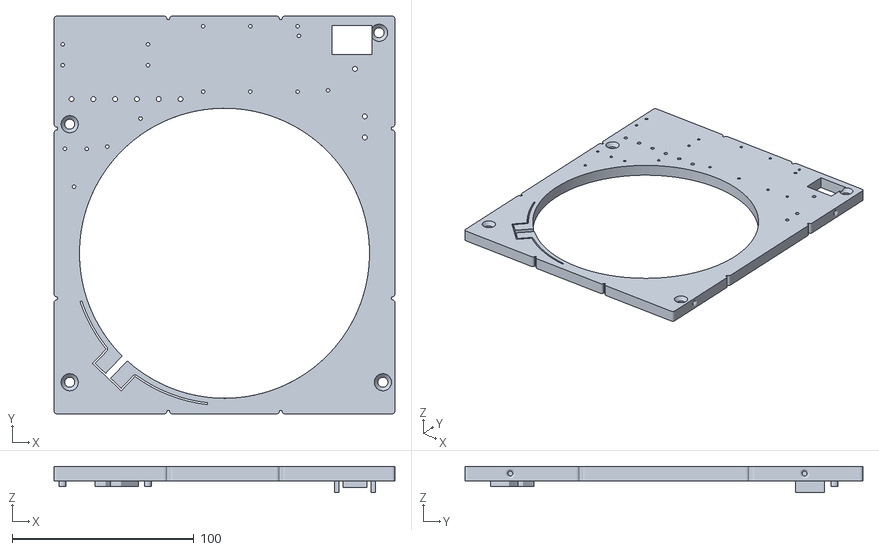
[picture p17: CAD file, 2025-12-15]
design/parts/common/stls/indoor_plate.stl
187.7 x 219.1 x 14.5

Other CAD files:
design/parts/common/stls/hat_seat.stl
design/parts/common/stls/standard_filter_adapter_plate.stl
design/parts/common/stls/fiberglass_grid.stl
design/parts/common/stls/noise_splitter.stl
research/cad_history/flow_straightener_v1_22deg.f3z
research/cad_history/noise_splitter_v29_experimental.f3z

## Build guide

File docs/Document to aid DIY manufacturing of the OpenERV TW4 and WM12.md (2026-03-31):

# DIY Manufacturing Guide: OpenERV TW4 and WM12

This guide provides technical specifications and requirements for the independent manufacture of OpenERV TW4 and WM12 units.

## Project Readiness
The OpenERV source code includes schematics, STEP/STL files, and a Bill of Materials (BOM). While the design is versioned, some manufacturing-specific configuration files (such as Prusa `.3mf` slicer profiles) are not yet included.

## Additive Manufacturing (3D Printing) Specifications

### Material Requirements
PLA is **not suitable** for these units as it lacks the required structural properties. The following materials are recommended:
- **Modified PLA (MPLA)**: Matter3D or Jayo brand.
- **High-Temp PLA**: Polymaker PLA Pro.
- **ABS**: Acceptable, though prone to warping/curling during large prints.
- **PETG**: Not recommended (insufficient rigidity).

**Thermal Limit**: The current polymers utilized start to soften at **55°C (131°F)**. This must be considered for hot climate installations or direct sunlight exposure.

### Slicer Calibration & Tolerances
To ensure parts fit correctly and maintain aerodynamic efficiency, the following slicer settings are recommended:

1. **Supports**: Use **Tree Supports** (Buildplate Only) for parts like the `combi_hood` and `noise_splitter`. This minimizes surface scarring inside critical airflow paths.
2. **Orientation**: Always align parts so that layer lines are parallel to the primary airflow direction. Refer to `print_specs.json` in the part directories for specific orientations.
3. **Dimensional Accuracy**: 3D printed holes (e.g., for the fan retention clamp) typically shrink. It is recommended to calibrate your slicer's **Hole Expansion** or **Horizontal Expansion** settings. 
   - A typical offset of **0.1mm to 0.2mm** is often required for a press-fit or screw-clearance fit.
4. **Bed Size**: Ensure your printer has a minimum bed dimension of **250mm x 250mm** for the `indoor_plate` and `outdoor_cover`.

### Component-Specific Settings
- **Noise Splitter**: Requires 100% infill in the pipe interface region for mechanical strength.
- **Regenerator**: Use the **Lines** infill pattern with **0 top and 0 bottom layers** to create the open-channel heat exchanger matrix.

## Assembly Requirements

### Electrical Specifications
- **Microcontroller**: Raspberry Pi Pico W.
- **Sensor Interface (I2C ID 1)**:
  - **SDA**: GP18 (Pin 24)
  - **SCL**: GP19 (Pin 25)
- **Power Control**: 10k Potentiometer on **GP28 / ADC2** (Pin 34).
- **Fan PWM Control**:
  - **Primary Fans (i0, e0)**: 70,000 Hz.
  - **Secondary Fans (i1, e1)**: 20,000 Hz.
- **Logic Level**: 3.3V (The Pico W is not 5V tolerant on GPIO).

### Hardware and Consumables
- **Wiring**: High-quality silicone-insulated wire (22-24 AWG) is recommended.
- **Insulation/Acoustics**: 
  - Sourced from indoor-side insulated ducts.
  - **Alternative**: 170 individual foam earplugs can be utilized as a acoustic damping medium.
- **Heat Exchanger Hats**: Currently require a custom mandrel for fabrication. (See `design/parts/common/stls/` for related components).

## System Architecture & Engineering Diagrams

### 1. Wiring Topology (Control Module)
The following diagram illustrates the standard wiring for the Control Module based on the Raspberry Pi Pico W.

```text
       +---------------------------------------+
       |         Raspberry Pi Pico W           |
       |                                       |
       |  [GP18] SDA <------> SDP810 SDA (Pin 4)|
       |  [GP19] SCL <------> SDP810 SCL (Pin 1)|
       |  [3V3]  VCC <------> SDP810 VDD (Pin 2)|
       |  [GND]  GND <------> SDP810 GND (Pin 3)|
       |                                       |
       |  [GP28] ADC2 <----- Potentiometer (W) |
       |                                       |
       |  [GP0]  PWM  ------> MOSFET Ingress   |
       |  [GP1]  PWM  ------> MOSFET Egress    |
       |                                       |
       |  [VSYS] 5V In <----- Buck Regulator   |
       +---------------------------------------+
```

### 2. Ventilation Cycle Timing
OpenERV utilizes a bidirectional airflow pattern. The timing is dynamically calculated based on the power level to maximize heat exchanger efficiency.

```text
Phase:     |   INGRESS (PID)   |   RAMP DOWN   |   EGRESS (PID)    |   RAMP DOWN   |
Direction: | <---------------  |      ---      |  ---------------> |      ---      |
Fans:      | In: ON / Ex: OFF  | All: COASTing | In: OFF / Ex: ON  | All: COASTing |
Duration:  | 45% of Cycle      | 5% of Cycle   | 45% of Cycle      | 5% of Cycle   |
```

## DIY Logistics
Specialized materials (polypropylene foam, specific acoustic fiberglass, electronic components) are typically sold in bulk. DIYers should account for the higher upfront cost of purchasing these materials compared to a pre-assembled kit.

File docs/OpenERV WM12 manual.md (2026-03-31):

# Introduction:

The WM12 is consists of two TW4 energy recovery ventilator (ERV)
modules, with a few electronic parts missing to reduce the cost, and a
foam adapter.

The TW4 energy recovery ventilator is meant to be a unit that is
embedded in a wall, to provide long term highly effective energy
recovery ventilation i.e. capture the heat and water vapor contained in
outgoing ventilation air, and transfer it to incoming ventilation air.

In the WM12, the foam, timber and hardware takes the place of the wall.

The TW4 modules are carefully designed to do this with high efficiency
and far lower low noise than anything else that does anything similar.

They include highly sensitive and accurate pressure sensors to regulate
the air pressure across the heat exchanger, thus regulating airflow into
and out of the house despite the chimney effect, wind, etc.

It's important to note that the unit is still in beta, and the modules
can be flexibly configured in many ways. This may appear to complicate
things but allows people to get what they need for longer term.

The machine is fundamentally capable of working to either prevent heat
and water vapor intrusion during periods of air conditioning, or prevent
the escape of heat during periods of heating, but the focus at first is
on cold climates, because parts that can stand high temperatures
encountered in hot climates are more expensive to make. The polymer
currently used for some of the additively manufactured parts starts to
get soft at 55 degrees C.

The WM12 can be controlled over WiFi using MQTT but it requires some
setup.

You can find the manual for the TW4 ERV here, where the WiFi related
features etc are discussed:
https://docs.google.com/document/d/1owr_riiIEUlUa45al_b7uIGe7IZfdDO1xxAAJC9aKUU/edit?usp=sharing

## General points to be aware of:

- **The silica gel coated heat exchangers may appear to have a smell
  upon first use** \*this is because they adsorb harmless chemicals from
  the packaging etc.\*. These chemicals are no more harmful than they
  are otherwise, but you can smell them primarily because they are added
  to otherwise fresh air, the smell is not covered up by other smells.
  There can only be so many milligrams of stuff adsorbed by the silica
  gel, and eventually it must all come out, or stay stuck in there. The
  smell should dissipate after a few days of operation, giving you
  outdoor air from then on. The material used in
  manufacture is non-toxic bio-source PLA, silica gel and isopropyl
  alcohol. There are no toxic substances used.

- Don't pull on the wires significantly, they don't have any strain
  relief, except the power wires.

- Remember Energy Recovery Ventilation is a long term value proposition.
  Although this machine has a remarkably fast payoff period as energy
  investments, or any investment, goes (less than 2 years on some
  contexts), it is meant to last a very long time. Be careful with it,
  position it in a place you are comfortable with the noise it produces,
  and ideally on a side of the house with minimal outdoor noise and
  wind. The components can be re-used to build a pair of TW4s for
  permanent installation in a dwelling for very long term, or re-sold
  while retaining their value. Additively manufactured/3d printed parts
  are not cheap or temporary, they can last a very long time and are
  relatively costly to produce.

<!-- -->

- The unit is capable of high airflow, 60 cfm is enough fresh air for a
  whole house by some measures. Most ERV units that advertise higher
  airflows will be revealed to not give anywhere near that in real world
  conditions if you actually check the manual/test data. A \$3000 large
  centralized unit in the basement of a house is only made to do about
  60 CFM during very cold weather, and it doesn't get very good
  efficiency, either, under such conditions.

- The system is quieter by far at any given airflow than similar
  push-pull units and centralized units, or any other ERV. It's also
  directly in the living space, however.

- **It may seem that the air exiting the unit is cold, if you put your
  hand in the air stream. However,** remember that any air colder than
  the surface of your hand will feel colder still if it is moving than
  if it is not. For comparison, try turning on a fan in a room, and you
  see the air exiting the fan feels colder. It is not, of course, any
  colder. Its temperature did not go down as it passed through the fan.
  We judge how cold things feel by the temperature of our hand, and how
  fast it changes. The faster the air is moving, the faster it extracts
  heat from our hand, and the lower the equilibrium temperature of our
  hand would be, should we leave it in the air stream long enough.

- If you wish to test/check the efficiency of the unit, a method using a
  low cost infrared thermometer is described elsewhere in this manual.

- The system takes a while to adjust the power level after the knob is
  adjusted. You will hear it adjusting but it takes a minute or two to
  adapt to large changes.

- Do not drop the unit, the printed parts are not strong enough to stand
  such forces. They can of course be replaced, all parts of the system
  can be replaced, but the labor and cost is significant. The machine is
  an investment. Treat it like a desktop PC when you are moving it, etc.
  Pick it up carefully with both hands, plan where you are going to put
  it ahead of time, unplug all cables before moving it, etc.

- The wind compensation similarly takes 30 seconds or more to fully
  respond, thus it is not effective in random gusty weather to block
  gusts, except to compensate for the average pressure.

- The beta units are made of MPLA. It is only good to 55 degrees C. The
  parts are not made for very hot ambient temperatures combined with
  direct sunlight. That will be addressed after proving everything in
  cold climates where such conditions are never encountered.

## Options to be aware of:

- Silica gel coating of heat exchangers. If it has a matte texture, it's
  coated with silica gel, which serves to absorb water vapor from
  outgoing air and transfer it to incoming air. This represents heat
  energy in some ways, because if there is lower humidity in incoming
  air, it accelerates the evaporation of water in the dwelling, and when
  water evaporates it absorbs a great deal of heat. The silica gel is
  the same material used in food packaging, it is non toxic and
  completely harmless. Very small amounts might come off on your hands,
  it is as harmless as sand.

<!-- -->

- The outdoor plate and hood unit allows the adaption of filters and the
  storm valve attachment, however recent changes with the sound splitter
  on the outdoor side have messed things up and I have not yet figured
  out how to use them in combination with the sound splitter in a window
  mount context/WM12. The old version with the plate and hoods and the
  fans inside the pipe is still an option if anyone needs the filter or
  storm valve modules while also mounting everything in a window.

  of components that are possible, especially with the wireless features
  of the TW4, you can put the two halves in different windows in
  different rooms etc, but I have not experimented much with this.

- The WM12 can be rotated and mounted sideways if the window is a shape
  that requires this, a window restrictor clamp should be used if this
  is done, to ensure it cannot fall out of the window.

## 

## Things during beta to be aware of:

- The initial units are made for cold climates primarily, extreme heat
  encountered in a desert could damage some components.

- Extreme heat has to be avoided during shipping, too.

<!-- -->

- The firmware is the exact same as the Leader of a pair of TW4 units.
  It has an auxiliary output for the second set of fans in the WM12,
  which is still active but not connected in a TW4 leader. In a WM12,
  only one side has a pressure sensor.

- I don't know for sure what will happen during extremely cold weather,
  like minus 30 C. Probably things will be fine, especially with the
  silica coated heat exchangers. It is very difficult to test.
  Simulations and calculations indicate some safety margin. However it
  is possible frost could accumulate on the heat exchanger or fan. This
  could cause temporary issues. The solution is to allow hot air from
  the house to exit the unit, melt the frost and evaporate the water,
  then start again. There are no provisions in the firmware for this
  right now. If the fans become stuck, you would have to take it out of
  the window, let it melt and dry and then put it back. The fans are
  waterproof. Future firmware updates may include functionality to
  detect cloggage with the pressure sensor and execute a defrost
  routine.

- The pressure detected by the pressure sensor is actually the pressure
  divided by about 4. This is because the pressure drops as the air
  flows through the narrow silicone tube, the sensor is not actually
  sealed and some air flows through it, however it still works very
  well. The pressure is divided in a repeatable and precise way, like a
  resistive divider dividing voltage, basically. Do not constrict the
  tube, or that would change things.

# Post-shipping assembly:

Consult the images to get an idea of how it goes together. Then, I
recommend the following approximate procedure, there are likely to be
details specific to your situation.

## Tools probably required:

- Ball end hex drivers, 2.5 mm and 3 mm, for the bolts and screws.

- Saw for wood

- You may or may not need a flat end screw driver, some of the clamps
  use hand-tightenable type mechanisms, some the screw head type.

- Some books or something else to prop it up on a table

- A table to work on for post shipping assembly.

- Box cutter with brand new/sharp blade to cut the foam.

- Sharpie to mark the foam and timber before cutting.

- Transparent or regular tuck tape (to attach the optional extra green
  pipe segments on the outdoor side) (some may be included, wrapped
  around the pipe segments).

## Part names:

### Heat exchangers:

{width="4.276042213473316in"
height="3.796357174103237in"}

### Noise splitter:

{width="3.4531255468066493in"
height="3.790764435695538in"}

### Mylar hat:

{width="3.213542213473316in"
height="3.5456911636045496in"}

### Noise splitter pipe extensions:

These extend the central pipe, reducing noise, they are not integral
because it gets too big to print, for now.

{width="3.651042213473316in"
height="2.3742530621172353in"}

### Wire extensions:

{width="2.9427088801399823in"
height="3.2132075678040244in"}

### Main pipe:

### Extra green pipe segment(s) for noise splitter (optional, reduces noise that comes in through the black foam by redirecting it downwards):



### Indoor cover and plate assembly, with pressure sensor:



### Indoor Plate and cover assembly with only 2 mosfet switches

Similar in appearance to the other cover/plate assembly.

### Black foam adapter

### Timber with hose clamps

This secures the pipes, acts as a handle and retains everything in the
window securely.

## Assembly procedure:

- Have a look at your window hold one of the main pipes in position,
  and, optionally, put the noise splitter on the pipe and have a look at
  how things are going to fit in the window. The timber should go across
  the window opening and then some, to make it practically impossible
  for the machine to fall out the window.

- Attach the clamps to the timber, and insert the pipes into the hose
  clamps, loosely. Have a look at how things are likely to fit in the
  window. Is there room for everything?

- Add the foam by pushing it onto the pipes

- {width="6.447916666666667in"
  height="4.566615266841644in"}

- Make sure the ends of the pipes are more or less flush with each
  other.

- See if it fits in the window ok, decide how to trim the pipes and
  timber. Mark with a marker or pen or pencil where to cut. See if you
  have room to add the little green pipe segments on the outdoor side.
  You can put the noise splitter on temporarily to check for fit.

- Trim the timber and the foam with a sharp box cutter for the foam and
  a saw for the timber. I used an oscillating saw so I don't have to
  take the timber off in order to brace it while cutting. You may need
  to remove the pipes from the clamps and brace the timber to cut it
  safely.

- Attach the extension wires to the connector coming out of the noise
  splitter.

- Attach the noise splitters. Get them in position and tighten the
  clamps on them.

- Put the hats on the top.{width="6.40625in"
  height="5.143646106736658in"}

- Place the left indoor cover (the one with the silicone tube) and plate
  assembly **near** the indoor end of the pipe. Attach the cable
  connector Then with the notch at the top (12 o\'clock position), put
  the silicone tube and the wire in the notch, and slide the heat
  exchanger into the pipe. This part is a bit tricky. You have to place
  the wire and silicone tube side by side in the notch of the heat
  exchanger, with the heat exchanger nearly in the pipe, with the tube
  and wires not overlapping each other. The tube and wires should not
  pinch or bind! Things should pretty much slide freely. If the tube
  gets squished, things will not work quite right.

  - Do not pull much on the silicone tube or you may pull it out of the
    sensor and have to open the cover and put it back in the sensor. I
    tape them or glue them on to the sensor to help with this but
    nothing sticks very well to the silicone. It's a hassle to get the
    cover back on after because of the wires.

  - Notice that the heat exchanger kind of slides around freely. This is
    not quite ideal but I haven't solved it yet. **\*when you pick up
    the machine, it can slide around\*.** **So keep the machine level
    when you pick it up, more or less. Remember it's supposed to be
    installed in a wall, not moved around like this.**

- Then rotate the heat exchanger 90 degrees, ideally, to prevent any
  stress or pulling on the tube. There has to be enough extra wire on
  both ends of the heat exchanger so things don't bind or get pulled on.

- 

- Repeat the procedure for the left side, but you can slide the heat
  exchanger in first, and then plug the wires in, because there is no
  silicone tube to deal with.

- Now would be when you add the pipe extensions to the noise splitter,
  they help improve noise rejection but are optional. It makes things
  kind of awkward to put n the table. \*Again be aware the heat
  exchangers can slide around inside the pipe if the machine is tilted\*

- Connect the two plates together, there is a 4 pin connector that is
  used, behind the plates.

- Ensure the clamps are tight enough, there are 6 clamps, one on each
  noise splitter and one on each indoor plate, and the hose clamps
  around the pipes. The ones on the indoor plate I rarely tighten and
  they require a ball end hex driver to reach in there anyway.

- It is a good idea to power it up while it's on the table, just to
  verify things seem to be working,

  - Do not work on it while it's in the window, it's tempting but you
    may push it out of the window or something. If you accidentally pull
    it inside the window you can knock the noise splitters off if they
    aren't on properly, or break them even.

  - The table blocks the airflow unfortunately during assembly. If you
    can, lift up the back while it's running and verify the airflow
    seems to be going the right way. Watch the behavior of the hats,
    that tells you if they are under negative or positive pressure.
    Don't get your finger in the fan! I put a two by four underneath the
    rear and front in order to prop it up for testing. It's a bit
    precarious like that.

- If the mylar hats have a dent in them, adjust the seating. If they
  collapse in that area while under negative pressure and make a noise
  in the process and you cannot solve it by adjusting the seating,, you
  can just add some gorilla clear tape to that area to prevent it from
  making noise when they collapse, this is a workaround for now. The
  thinner the mylar the better the anti noise performance so it is
  pretty close to the limit. The slight dent formation is otherwise
  safe.

# Handling/window installation

## Moving the machine:

1.  Don't leave the power supply connected, disconnect it every time you
    move the machine, to simplify things.

2.  If the wooden window timber retainer is assembled correctly, it can
    be used as a handle to pick up and move the machine. Ensure the
    clamps are reasonably tight before picking it up.

3.  If the machine is tilted during motion or knocked around, the heat
    exchangers may slide around. Try to keep it more or less level to
    avoid this.

Plan each move, make sure there is nothing to trip over etc.

If anything doesn't fit or is awkward, patiently back off, put things
back, correct it and try again.

Make sure everything is properly in place and connected/tightened and so
on so nothing is going to fall off and plummet downwards, on the outdoor
side especially.

Adjust the position of the wooden window retainer before putting it in
the window. Don't loosen the hose clamps while it's in the window to
adjust the position, tempting as it may be, you may end up dropping
something out the window.

Do not pull the pipes/unit inwards while the unit is in the window, if
the outdoor components are not attached firmly they could be pushed off
by the window sill and plummet downwards.

## Normal installation in a window

You first should assemble the unit on a table, and test it to verify
there are no wiring errors etc, as it's much easier to correct things at
this stage.

Ensure that the noise splitter is fully secure on the pipe, attempt to
rotate them relative to the pipe to ensure they are secure. The bolt
does not need to be very tight to ensure a great deal of friction. Do
not overtighten the bolt or it will break the clamp.

Ensure the indoor cover(s) is/are reasonably secure, and also it's very
important the hose clamps are secure around the pipes.

Check things can fit in the window. This is not so easy, you may need to
use a measuring tape, and if you can, open the window wide and lift up
the unit (after full assembly is completed) and see if it mostly fits.
Sometimes the noise splitters hit the window sill. If this occurs, a 2
by 2 can be put on the lower part of the window to raise the assembly
but it is a hassle to seal everything.

You can change things in some ways, such as by rotating the noise
splitters so that things fit.

Don't worry if you crumple the mylar hats a bit, it appears to be
harmless.

After you have a sound plan, you can trim the extra included black
polypropylene foam, tape it to the other foam, and move it into
position, close the window, and put the window restrictor clamp in
place.

I usually close the window around the pipes themselves, with the foam
overlapping on the interior side, as I have found it easier to seal like
this.

It appears to be a good idea in some cases to tape the timber to the
foam, as it makes it easier to seal all gaps later around the window,
when this is done. It's hard to get tape in there when it's installed in
a window.

You can lift the unit safely by grabbing the timber, when the hose
clamps are secure, the only remaining problem is the heat exchangers can
slide around if they are not a tight fit. Making them a tight fit makes
things harder sometimes so the best thing is to keep the unit level at
all times and make sure the interior covers are secure against the pipes
so if they do slide around it doesn't knock the covers off and tumble
out.

The next unit I ship will have a different timber, shorter, with metal
pieces ("mending plates") extending off the end, to make shipping
cheaper, as the long timber was expensive to ship. You will measure your
window and screw the metal pieces in place such that the total length of
the metal pieces and the timber is slightly longer than your window is
wide. Thus it is practically impossible for the unit to fall out the
window in landscape mode.

If you need it to be longer because you have a very wide window, you may
need to purchase a timber locally from the hardware store and cut it,
then attach it with a screwdriver (robertson, #2 I think, the green
one), depending how secure you want it to be.

I recommend taping the edges of the foam and window shut with gorilla
clear tape or similar. Otherwise strong winds can blow significant
amounts of air through even small cracks. You don\'t generally want to
remove it very often. It doesn't look great but I see no other way to
really seal things easily.

Access to the outdoor side is useful for various reasons, to inspect
etc. It can be an awkward fit due to the sill on some windows, usually
the outdoor sill, but I have been able to shimmy it into every window I
have tried thus far.

- There should be a small metal clamp like object included in the
  package. This is the window restrictor. You clamp it to the window in
  some area to prevent the window from opening too widely, which could
  allow the machine to fall out. Strategize for when and how to add this
  before putting the unit in the window.

Just like a window air conditioner you should be very careful:

- Be extremely careful not to allow the machine to fall out the window.
  The timber across the top plus the mending plates is supposed to be
  long enough that it is quite hard for it to accidentally go out the
  window.

- You may find that the exterior part hits the outside window sill/the
  exterior wall. If this happens you may need to remove the extra little
  green pipes or not add them, or you can raise the unit up by putting a
  timber below it, in the window. Most people don't add them although
  the 45 dBa at max power is with them, not without them. The unit can
  rest on the exterior window sill and the foam still seals and
  everything works fine, in my experience.

- Do not try to move the unit with the power attached, it gets awkward
  and looks like it would considerably increase the possibility of
  accident. Also you could break something if you pull too hard on the
  power cable. Unplug the power supply and otherwise simplify things as
  much as you can before moving the device.

- You can use the timber across the top as a handle to move it around.
  Again, try no to tilt it because the heat exchangers can sometimes
  currently slide around relatively easily, I have no good solution to
  this yet.

- Remember when you turn it on that 60 cfm is a lot of air as ERVs go,
  it's as much as some full sized centralized units get during cold
  weather. If it seems a bit loud on max, that's because it's a lot of
  air and power, not because the machine is inherently noisy. It has an
  excellent noise to flow/efficiency relationship, however it also has a
  relatively high maximal power capability.

## Sideways installation

It is possible and practical to install the machine sideways. Below are
some candid photos of an actual installation.



In this photo, the interior cover is oriented in a way such that the air
would come out the side and get re-inhaled by the other heat exchanger.
I recommended putting some tape over the outlet on that area.



The noise splitters are rotated to get them to fit despite the window
sill. Theoretically longer pipes could also work, or a timber as a
spacer.



# Repair and maintenance:

## Overview

The system is made to be maintained over the very long term, thus giving
good return on investment. The wiring is the hardest part, the schematic
is pretty simple as such things go but it is easy to put a wire in the
wrong place, **or allow a stray strand of the multi core wire to touch
the wrong place (this is a common issue so watch for it. Always twist
the multiple strands around each other before inserting in a connector
to avoid this)**.

The electronics are all standard and basic, except the pressure sensor.
The connectors are relatively user friendly. In the event of power
surges, angry exes, etc. any damaged component can be replaced, even if
the original company is gone. 50% of home improvement companies are out
of business within 5 years, so warranties are not enough.

## Fan replacement and/or bearing replacement:

Any 120 mm fan can be used, 2, 3 or 4 pin, you just need to cut the
corners off. The main issue is getting a fan that is quiet, and water
resistant, and ideally ball bearing, and high pressure. If you cannot
get waterproof fans, silicone waterproofing grease (such as marine
dielectric grease, which is used on ships to waterproof electronics) can
be painted with a brush onto the electronics of almost any ball bearing
120 mm fan. These fans can be dismantled just by removing the sticker on
the back and removing the circlip (small torx screwdrivers work to
remove the circlip). There are waterproofing sprays for electronics that
could be simply sprayed in there, but they are not common and I have
tried only one with limited success. Silicone oil is basically what
you'd want. Mineral oil would probably work fine too.\
\
The printable components can be printed by any cloud printing company,
or ideally a real person who just has a printer in the local area, which
tends to be a lot cheaper (makexyz.com is one option).

The included fans can have their bearings replaced, and the bearings
should last 7-12 years. The bearings cost only about 20 cents each and
are widely available, standard bearings.

### Bearing replacement instructions:

**Bearing size:** OD: 8 mm. ID: 3 mm. Thickness: 4 mm.(3x8x4 bearing).
If you search 3x8x4 bearing you will see a lot of people selling them in
small quantities. The ABEC rating and noise level doesn't really matter
much, in any case small time sellers usually claim more than is true,
unless you are actually buying from mcmaster-carr or directly from a
supplier.

**The circlips:** Are 3 mm outer diameter circlips. You may not need to
buy one, you can usually re use the old one, but if you lose it or break
it you can get replacements easily, get the kind with the little hooks
or complete holes on the end, ideally. Alloy is fine, stainless is
overkill.

You need to dismantle the system to get the fan on a table in front of
you, then remove the sticker covering the bearings, remove the circlip,
and the fan blades/magnet assembly just falls right out. The bearings
just fall out, you put the new bearings in and then put the circlip back
on.

To remove the circlip is the hard part. Circlip pliers of the right size
are hard to get and expensive, however I have found a good technique
using two very small torx screw drivers. You need 1-0.8 mm or smaller
torx heads. Place the two screw drivers together and push down while
levering them against each other (the handles of the screwdrivers make a
usable fulcrum point, you can tape them together to make it a little
easier) to cause the tips to spread apart. The bearing has a spring
behind it, when the circlip is released the bearing will pop up. *The
circlip may also sproing away and be lost, so be ready.*

Putting the circlip back on is a bit difficult. You can finagle it back
on with the screw driver, I've found that to be workable, but an even
easier way is to drill a 3 mm hole in the end of a 7 mm diameter hot
melt glue gun refill. It's basically a soft polymer rod. The hole
squeezes over the shaft, but the edge of the hole pushes the circlip
down nicely, until you feel it click into place. You only have to do
this every 7-12 years!

Electrical schematic:

The colors in the schematic should be the actual wire colors. Beware red
is used for both 5v and 3.3 volts. !2 volts is Yellow. Black and brown
are ground. Orange is for the ingress fan, green is for the egress fan,
both the signal to the mosfet board and the ground side of the fans.
Orange and green is also used for the pressure sensor data and clock
signals, which is which is in the schematic.

The part descriptions for electrical parts are in the BOM.

There is a PDF in the source code repository with the schematic, it is
not copied here because it's too laborious/difficult to maintain to make sure the
various copies are always up to date if there is a change or bug
correction. You have one copy in one place and then refer to it as
needed. When things are out of beta it will be copied here.

## STL files for replacement printable parts:

See source code repository. It's a google drive linked to on the
website, and will be put in the internet archive for long term if
possible.

### 

### Note on printing the regenerator/heat exchanger:

The latest and greatest heat exchanger is produced directly with python
script generated gcode specific to the printer I use and cannot be
practically produced diy, unfortunately. However the old model can be,
and the STL is included for that, in the source repository. To do this,
simply use Cura, load th STL in, put it in the center of the build
plate, and set it to do "lines" infill with about 2.5 mm on center
(between centers of the lines) spacing and 0.45 mm width, no top layer
and no bottom layer (set them to zero). Check the preview and it should
show you a structure which is much like grid infill, parallel channels
which are square in cross section, with the outer wall. Tape can be
applied over the nubs on the side to fit in an oversized pipe, or they
can be sanded if the pipe is too small. You could also use grid infill,
but the roads tend to have problems where they intersect. When the
nozzle goes over one road, it wipes the plastic off, and not enough is
deposited on the lee side. I don't know how to solve this in Cura
without using lines infill. If you could make it so the nozzle went in
alternate directions each layer that would probably solve it well
enough.

## Replacement part numbers/sourcing:

The connectors are called pluggable screw terminal connectors, 3.81 mm
pitch.

The screws are stainless steel self tapping screws hex socket stainless
steel 304.

The part number of the fans is 11925SE-12R-FT-DW . They are available
from digikey and other electronic parts overnight supply houses.

The plastic sheet for the hats is 50 micron generic BOPET, biaxially
oriented polyethylene terepthalate, (generic mylar, mylar is a brand)
but 75 micron (3 mil) might be a better bet, some 50 micron is crinkly
and makes noise.

The adhesive is E6000, waterproof elastomeric adhesive.

The wire is silicone multi stranded wire, 24 gauge is fine for repair
stuff.

The pipe is SDR35 PVC pipe, SDR28 will NOT fit SDR35 ABS is \*not\* the
same size.

The thin transparent tape is gorilla clear.

# Efficiency:

Testing is ongoing, initial testing results indicate 87% sensible heat
recovery efficiency at 60 cfm and 75% latent heat recovery. Efficiency
is even higher at lower flows, exceeding 90 percent at 30 cfm.

## Ventilation efficiency/short circuiting:

There is a measure in the HVAC industry/building design called
ventilation efficiency. It's basically the ratio of the indoor air
quality vs the ventilation rate, or the indoor air pollution vs
ventilation rate, assuming a constant release of pollutants in the
building. There are many clever ways such as displacement flow
ventilation, to improve this above the basic so called dilution flow
approach, which is the normal approach commonly used, where a jet of air
just swirls around in a room and mixes thoroughly, and air is removed
practically randomly from the room. One thing that puts a dent in
ventilation efficiency is so called short circuits, which is a bit of a
misnomer, but it it implies fresh air transiting rapidly to the
exit/exhaust, without doing anybody any good.

Obviously the WM12 has the intake and the exhaust right next to each
other, but they are pointed in opposite directions. I have used smoke to
viualize airflow and posted a video of this on youtube. There is no
re-inhalation of air near the unit. The exiting air jets away and mixes
into the room effectively.

The only case where there is a significant although minor concern is
when the unit sticks over a window ledge, in that case some air at the
bottom near the ledge tends to swirl back in. To solve this, a piece of
paper or cardboard can be used to guide the airflow.

# Savings/investment calculations:

See spreadsheet
[[here]{.underline}](https://docs.google.com/spreadsheets/d/116Zo_kcxLSTzkiw5lbofJJ0vPNLvXxe8Esu2196i8oA/edit?usp=sharing),
it is also linked to on the website, to determine the actual return on
investment that applies to you, in your area, with your energy prices.
The machine is an investment, its value arises from long term operation.

# Specifications:

  -----------------------------------------------------------------------
  Spec                                Value
  ----------------------------------- -----------------------------------
  Max actual net fresh air flow       60 CFM

  Power supply voltage                12 Volts

  Power supply current requirement    1.5 Amps max (during fan
                                      acceleration)

  Expected actual average             87%
  season-round efficiency at 60 cfm,  
  including water vapor/latent heat   
  if silica gel coated. Varies little 
  with conditions.                    

  Expected actual average             90%
  season-round efficiency at 30 cfm   
  including water vapor/latent heat   
  if silica gel coated. Varies little 
  with conditions.                    

  Noise emission at 1 meter in front  30 dBa
  of unit, at 15 CFM                  

  Noise emission at 1 meter in front  35 dBa
  of unit, at 30 CFM                  

  Noise emission at 1 meter in front  45 dBa
  of unit, at 60 CFM, with optional   
  extra pipe segments                 

  Wind resistance rating (from        S1 (less than 6 CFM at 20 pascals
  in-house measurements, not yet      wind pressure, total excess flow in
  certified)                          or out). It's actually better than
                                      this.

  Average power consumption at 60 CFM 9 Watts

  Average power consumption at 30 CFM 5 Watts

  Design life                         Parts can be replaced indefinitely.

  Fan bearing life span, expected     7-12 years elapsed time during
                                      normal use

  CE mark certification               Not yet.

  Underwriter's laboratory            Not yet, the power supply is UL
  certification                       listed, though.
  -----------------------------------------------------------------------

Rohs compliant.

Contains no toxic or hazardous materials.

Made in freedom.

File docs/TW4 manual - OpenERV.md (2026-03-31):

# TW4 Energy Recovery Ventilator Manual

V1.0 BETA

# Introduction

The TW4 energy recovery ventilator is a machine that harvests heat
energy and water vapor from outgoing ventilation air, and transfers it
to incoming air. It has ten to about 28 times the performance to cost
ratio and rate of return on investment of the next best machines in its
class (decentralized), and about four times better than even the next
best energy recovery ventilators available for home of the ducted type,
if you already have the ducting even, depending on how you count it.

It is made to last for a very long time, free of planned obsolescence,
and to be produced in a way that provides living wage jobs that have
relatively good working conditions and an open future.

It is made partly with methods and techniques that are normally
considered for prototyping. This makes it very flexible and has allowed
me to refine the design in several departments to a much higher degree
than is conventionally possible.\
\
However it is for now still in beta. Also each unit is assembled partly
by hand. This manual is focussed primarily on the fully assembled and
tested units (except they need to be partially dismantled for shipping
and installation).

# Unpacking/checking everything is there and not broken

Parts/packing list:

  -------------------------------------------------
  **Heavy duty attenuator, fabricate    quantity
  your own attenuator version**         
  ------------------------------------- -----------
  item                                  

  Indoor plate/cover module             2

  fan module                            2

  extension cables                      2

  power supplies                        2

  Heat exchangers                       2

  **Splitter version, with pipes**      

  item                                  

  printed noise splitter with bolt and  2
  nut and fans installed                

  Splitter mylar hat                    2

  extension segment (3 pin connectors   2
  on both ends)                         

                                        2

  pipes                                 2

  -------------------------------------------------

*Table 1.*

# Anatomy of the TW4 and how it works in general - heavy duty sound attenuator version

## Anatomy 

## Indoor plate and cover module:

## Indoor plate with cover removed:

*Fan module for heavy duty attenuator version.*

## 

## Issues to be aware of in general

- Do not pull on the wires on the connectors, the metal from which the
  wires are made is not that strong. Disconnect the connectors by
  exerting force on the body of the plastic connector area, not by
  pulling on the wires.

- If the power level is less than 17% (software cutoff), it gets rounded down to
  zero.

- The software limits the maximum pressure setpoint to **34 PA** for TW4 units to protect the fan motors and maintain efficiency.
- If the power level is zero percent, the system will try to maintain a
  zero pressure across the heat exchanger i.e. pressure regulation is
  still active This may cause the fan to actually be on slightly if
  there is a static pressure caused by wind or other forces. It is
  fighting unbalanced air intrusion, which eliminates unwanted heat
  loss.

- The networking/communication only happens once every cycle. A cycle is
  between 50 and 90 seconds long, depending on the power level (longer
  for lower power levels). So commands from MQTT and propagation of
  power level from leader to follower can take up to 90 seconds.

## Description of overall working process during energy recovery mode

Basically each TW4 module has a pressure sensor that detects the air
pressure across the heat exchanger and regulates it to the commanded
level using 2 separate Proportional Integral (PI) control loops, one for
ingress and one for egress. It stores state of the applicable control
loop and switches from ingress to egress or egress to ingress then
restores the state of the applicable control loop every 20-45 seconds
(half the "Ventilation Cycle duration").

This causes it to compensate for wind, up to reasonable wind levels, but
the fans are not able to compete with strong winds. There is an
automatic storm valve add on which can be used in the future to block
the system in the event of a storm.

The Ventilation Cycle duration is determined partly by the power level, it is longer at
lower power levels to further reduce perceived noise and improve average
flow (flow is suppressed slightly during the direction reversal).

The leader and follower synchronize their clocks over wifi so the fan
reversals are synchronized.

They synchronize by the leader broadcasting UDP packets at the start of every Ventilation Cycle (UDP Port 12345),
containing the clock time and power level. A cycle is a full
ingress-egress cycle. It therefore takes up to 90 seconds for
information to propagate. The follower will not turn it's fans on unitl
it receives a synch packet, for every cycle.

The knob on the follower is inert, it will be used in the future with a
firmware update that allows the power level to be changed using either
knob.

The power level can also be changed over MQTT, and can therefore be
controlled by a smartphone or home automation system.

The leader needs to know the ip address of the follower, it must be in
the configuration file. The devices ship by default with this already
configured.

The devices work as is by themselves out of the box, but if you want to
connect to wifi for additional features, you need to edit the
configuration file using a program called Thonny running on a desktop or
laptop, and a usb-micro cable.

The microcontroller runs Micropython, a human readable and easy to edit
yet full powered programming language. The programs are not compiled,
they are stored on the microcontroller, called a Pico W, and can be
edited like a text file on a thumb drive through a program running on a
PC called Thonny. The PC connects to the Pico using a micro usb cable.

The configuration of the TW4 is drawn from a file on the pico,
persistent_vars.json. This is a text file which is also machine
readable. You can edit it directly but be careful not to insert extra
spaces in the wrong place or whatever. Capitals matter, everything has
to be exact.

Future features will include the ability to do only ingress, only
egress, or slightly pressure bias in one direction, and control each
module separately.

# Sound attenuation choices

## Heavy duty sound attenuator 

The TW4 can be used with a heavy duty sound attenuator made using
hardware store parts and pipe, which also blocks a lot of
traffic/exterior noise, or a 3d printed "noise splitter" which is
cheaper and lighter and blocks the fan noise about as well but does not
block as much exterior noise.

Right now the heavy duty attenuators are not for sale from me, you just
make one yourself, because shipping would be costly and all parts are
available locally, and this allows me to focus on the core offering.
There is a document here which describes it and the assembly/fabrication
process:

[[https://docs.google.com/document/d/1jhOIYxr6VYDhxBGIlXFxPUYev6MeVffLbuaWy17LuUc/edit?usp=sharing]{.underline}](https://docs.google.com/document/d/1jhOIYxr6VYDhxBGIlXFxPUYev6MeVffLbuaWy17LuUc/edit?usp=sharing)

{width="2.2083333333333335in"
height="8.666666666666666in"}

## Sound splitter

The default option is a cheaper, lighter, smaller option, which blocks
the fan noise about as well but does not attenuate exterior traffic
noise etc. as well. The fans are on the bottom of the white plastic
object. The "hat" on the top is acoustically transparent - sound tends
to mostly pass right through it. The fan noise comes up the central pipe
and goes right through the hat, while the air makes a few turns and goes
into the green pipe. The hat is conical so it can resist negative
pressure while air is being sucked out of the house. The uv resistance
may be less than the heavy duty attenuator, the hat may need to be
replaced after 20 years. It is just mylar (BOPET).



## Further attenuation

There are two tricks, which I do not employ due to complexity and cost,
but can be employed by a do-it-yourselfer who seeks further noise
reduction.

One is the replacement of the fiberglass in the interior cover with
viscoelastic foam. Earplugs can be used. It takes about 180 standard
earplugs. Mosquito mesh might be a good idea under the grille, to keep
them in reliably. See picture below.

The second is to use viscoelastic foam to line the pipe in some region,
either before or after the heat exchanger. This requires the pipe to be
longer than the heat exchanger, but this may occur anyway with some
walls, and it can stick out on the exterior side. A space needs to be
left between the end of the foam and the beginning of the heat
exchanger. The foam will need to be removed in some circumstances, so
don't glue it in place. A 3d printed mesh-walled can of about 148 mm
outer diameter - the inner diameter of the pipe is 149 but it's not
always that round - with no center (so the air can flow through the
center but sound waves that hit the walls are largely absorbed),
basically, filled with earplugs, would make a lot of sense actually, as
a good diy option. Again, use modified pla, not standard pla or it's
likely to crack over time. The longer this segment is, the better, I
only tested one segment 10 cm long.

Both of these measures, during testing, gave reductions of 2-3 dBa each.
Together they could provide considerable reduction, allowing the TW4 to
operate at 60 CFM with only 35 dBa of noise or something, but I have not
tested everything together actually installed in a wall yet. The sheets
of foam are hard to source, and I have no good sources for them.
Neoprene foam is commonly used in this role but I don't think it would
work as well as viscoelastic foam. The earplugs work pretty well and
they aren't prohibitively expensive for a one off diy thing that will
last for many many years. Remember they lose their viscosity properties
if they are washed, they become elastic only, so probably not a good
idea to let them get wet either.

These measures may be attractive if the unit is used in an office or
bedroom.



## No attenuator option

The fan module used with the heavy duty attenuator can also just be
inserted direction into the pipe, cutting costs. It should probably be
some distance inside the pipe at least, to prevent inhalation of rain.
The fans are waterproof, but you don't want rain getting sucked in and
then blown inside. A pipe elbow or similar can be used as a hood, there
are also hoods made from sheet metal that connect to a six inch pipe.
This does not provide much sound attenuation and would be only suitable
in the case of a basement or cafe something where noise is not
important, due to the lack of people or due to high ambient noise
anyway.

{width="5.322916666666667in"
height="5.7105304024496935in"}

The interior cover also contains fiberglass which helps attenuate noise
quite a bit. This is always included.

# Accessories

I have designed an exterior plate to which filters, valves, etc. can
attach, which clamps on to the green pipe, and also to the bottom of the
noise splitter. You can rotate the sound splitter sideway or leave it
upright. Same for the heavy duty attenuator, rotating it sideways might
get complicated because it would be heavier on one side than the other,
exerting some rotational force.

To this plate can be attached a hepa filter, as shown below. It is a
Bosch HEPA filter for a car. Adapters can be produced for other filters.
There is an adapter for 8 inch furnace filters but the filters
themselves may not do well in the rain. There is also a storm valve
available.

filter module attached to plate{width="4.625in"
height="5.90625in"}{width="4.90625in"
height="5.6875in"}{width="4.208333333333333in"
height="5.177083333333333in"}

# Qualitative features list

- **Very short payoff period.** This is the ratio of the capital cost to
  net financial savings, given the cost of energy. This varies from 1.5
  years for electric resistance heat to 3.5 years for heat pump supplied
  heat, depending on the area, both how cold the weather is and the cost
  of energy and how high the unit is turned up. See spreadsheet on the
  website for details specific to you.

- Can be controlled over wifi, including by using a bridge to Alexa,
  Google Home, Matter and other home automation systems, and from a
  phone using MQTT apps.

- Repairable, this improves the payoff period by extending de facto
  lifespan and reducing maintenance cost.

# Beta issues to be aware of

- The follower takes a full cycle to get an update regarding the power
  level from the leader. **So if you change the power level with the
  knob or mqtt, it may take from 50 to even 90 seconds (the lower the
  power level the longer the cycle period) to stabilize/update
  everything. This will be improved with a future firmware update.**

- There is no way to configure the modules/pair with an easy web
  interface or anything. You have to connect by micro usb cable and edit
  a configuration file. A configuration file is used, but a bit of a hassle. You aren't
  expected to do it very often.

- The fit of the sound splitter to the pipe is a bit tight, chamfer the
  pipe edge to get it on.

- The fit of the indoor plate is a bit tight, chamfer the pipe to get it
  to fit easily. You don't really need to tighten the screw, it is
  redundant.

# Performance specs, per pair of modules:

  -----------------------------------------------------------------------
  Spec                                Value
  ----------------------------------- -----------------------------------
  Max actual net fresh air flow       60 CFM

  Power supply voltage                12 Volts

  Power supply current requirement    1.5 Amps max (during fan
                                      acceleration)

  Expected actual average             85%
  season-round efficiency at 60 cfm,  
  including water vapor/latent heat   
  if silica gel coated. Varies little 
  with conditions.                    

  Expected actual average             90%
  season-round efficiency at 30 cfm   
  including water vapor/latent heat   
  if silica gel coated. Varies little 
  with conditions.                    

  Noise emission at 1 meter in front  30 dBa
  of unit, at 15 CFM (printed         
  splitter or heavy duty attenuator   
  are about the same.)                

  Noise emission at 1 meter in front  35 dBa
  of unit, at 30 CFM                  

  Noise emission at 1 meter in front  42 dBa
  of unit, at 60 CFM, with optional   
  extra pipe segments.                

  Wind resistance rating (from        S1 (less than 6 CFM at 20 pascals
  in-house measurements, not yet      wind pressure, total excess flow in
  certified)                          or out).

  Average power consumption at 60 CFM 9 Watts

  Average power consumption at 30 CFM 5 Watts

  Design life                         Parts can be replaced indefinitely.

  Fan bearing life span, expected     7-12 years elapsed time during
                                      normal use

  CE mark certification               Not yet.

  Underwriter's laboratory            Not yet, the power supply is UL
  certification                       listed, though.
  -----------------------------------------------------------------------

*Table 2.*

Rohs compliant.

Contains no toxic or hazardous materials.

Made in freedom.

# Installation

## Installation of the pipe

As of October 13, 2024, it remains on my list of things to do to
actually install a 6 inch pipe in a wall myself. However there are many
different types of walls, exterior coverings and so on. For this reason
it is not a simple undertaking and I cannot provide specific
instructions or advice specific to any given situation, aside from:

- The importance of avoiding avoiding plumbing and electrical lines and
  load bearing elements

- That it is a common procedure for many reasons and most good
  contractors know how to do it

- The pipe needs to be sealed on the exterior side effectively, where
  the house wrap is, and also on the vapor barrier side,

- and mechanically secured in the wall effectively, using caulk or PU
  foam, usually.

- The drill is kind of big and heavy and exerts a lot of torque, and
  looks like it would be hard to hold in place while drilling, for just
  one person.

- There are other ways aside from a core drill to cut a hole in a wall
  which are easier in some ways and harder in others.

- The pipe should be slanted 2-3 degrees to allow any water to run to
  the outdoors, this is true of almost any through-wall pipe.

- Be very careful the pipe sticks out enough on both sides.

- It may help to chamfer the ends of the pipe to get the other parts on,
  this is strongly recommended. Aggressive sandpaper or a chamfer tool
  can be used.

The standard core drills are slightly larger than the pipe (150 mm is
the nominal dimension, it is 159 mm diameter on the outside, typical
core drill of this size is a 162 mm drill) so you do not need to make
the hole slanted on purpose, generally. Just cut it perpendicular to the
wall and there is enough space to slant the pipe.

Rubber wall grommets can be had for about \$15 each and are a good way
to seal the pipe to the vapor barrier or house wrap in a new build
especially, but are a bit hard to use in a retrofit. Polyurethane foam
and Tuck tape is generally the way to go with retrofits.

To cut a pipe square, there is a good trick using a band of plastic (can
be packing tape), or sheet of PET or sheets of paper taped together.
Make a single sheet that is at least 490 mm long (larger than the
circumference of a 159 mm diameter circle, which is the pipe), and wrap
it around the pipe such that it overlaps precisely with itself at the
ends, then tape it with masking tape to itself. This forms a circular
edge around the pipe which is aligned perpendicular to the central axis
of the pipe. Trace around the edge of this wrapped piece of paper with a
sharpie and you can mark the pipe effectively, then cut it with a hand
saw.

## 

## Electrical supply

You need to decide which kind you want, It is recommended to the wall wart at
first and you can always hard wire the electricity later. You can even
take a power supply of the type that can be used for hard wiring and
just put a plug on it and use that so you don't end up with an extra
power supply when the dust settles, and you have it for when you want to
hard wire it.

### Hard wired

Power supply goes in a junction box.

Power switch (a standard wall light switch is fine) goes before power
supply, not after. It needs a junction box too, of course. It can be the
same box as the power supply.

Electrician has to install the wires, or you can DIY carefully, the low
voltage side is easy but be careful on the 120 volt side.

### Wall wart style

This is a simple approach using a power supply that plugs into the
nearest outlet. You can get extension cables for these power supplies if
the cable is not long enough.

You can do a combination of wall wart and concealed wires using flat
speaker wire on the wall that can be painted over or similar.

## Installation of components after power supply and pipe is taken care of

Pictures coming before exiting beta.

Tools required:

- 1 2.5 mm \*ball end\* hex driver. A non-ball end will not fit to
  secure the indoor cover until the design is changed in this regard,
  but you also don't really need to tighten that screw, the cover stays
  on pretty well without it.

Procedure:

1.  Plug the extension cable into the fan.

2.  Put the sound attenuator on the outside and the extension wire
    through the pipe.

3.  Secure the sound attenuator to the through wall pipe: it may be a
    good idea to use some tape to secure the large heavy duty
    attenuator, just to be extra sure it cannot rotate due to high winds
    or anything as it is heavier on the top than the bottom. Transparent
    tuck tape is good and looks good.

4.  Make sure the indoor edge of the pipe is chamfered.

5.  Make sure the power supply is **not** connected to 120 volts, i.e.
    is not plugged in, or the switch is off, ideally turn the circuit
    breaker off.

6.  Remove the cosmetic cover and connect the DC power wires to the
    terminal block if you are using that kind of power supply option,
    otherwise there should be a 5.5 mm jack hanging out the side, so
    there is no need to remove the cosmetic cover. **Do not get the
    polarity backwards. Test with a multimeter if there is any
    uncertainty. Red is positive, black is negative for DC.** You can
    put the plate on the pipe for this step but you may need to take it
    off again in a minute.

7.  Put the cosmetic cover back on. You may need to take the plate off
    the pipe for this, and get someone to help hold it. Unfortunately it
    is a bit awkward to connect the power and then stuff the wires back
    under the cosmetic cover. It's even harder if the interior plate is
    already on the pipe, because you can't reach in to stuff the wires
    into posiion. I have no good solution for this right now except to
    organize the wires so it's easy to take the cover off/put it back on
    while the plate is attached to the pipe.

8.  Hold the interior cover/plate assembly in one hand, connect the
    extension wire for the fans to the assembly, and you have to finagle
    the pressure sensor tube and the wires into the notch at the top of
    the heat exchanger and slide the heat exchanger into the pipe,
    without pinching or jamming. Things should slide in with little
    force. There should be enough tube and wire to allow the parts to be
    held apart while doing this. Do not pull hard on the sensor tube or
    wires. The wires and tube should both slide if pulled on very gently
    in the notch when done. The tube cannot be pinched.

9.  Once the heat exchanger is in place, put the interior cover/plate
    assembly on the pipe. It's a bit of a tight squeeze. The plastic is
    flexible and will expand, but you may need to "hook" one side on
    only slightly and then progressively push the edge over the pipe.
    The edge of the pipe should be chamfered alraedy. The edge of the
    indoor plate is chamfered.

10. Think about if you may have forgotten anything

11. If not, you can connect the 120 volts, by plugging in the wall wart,
    or turning the light switch on, for a hard wired scenario.

12. The follower does not do anything unless it gets a synch packet from
    the leader so it won't appear to do anything until the other of the
    pair is also installed and powered up. If it still doesn't seem to
    do anything, use the troubleshooting section.

13. The plan during beta phase is to pair beta units at the factory so
    you don't have to do any setup unless you want them to be accessible
    over your home wifi network. If you need them to be available on
    Wifi, see the initial setup section.

# Initial setup

The devices work out of the box, but if you want to use additional
features, you need to edit the configuration file using a program called
Thonny and a usb-micro cable. See below for details on how to do that.

## Using the TW4 without any external wifi network

For convenience or security etc. you may not want to connect the TW4 to
your home wifi network. In that case, the TW4 leader can start its own
access point. It is a typical wifi access point in most regards, other
devices can connect to it and talk to each other through the Pico.

When factory default TW4 leader is booted up, it starts an []{.mark}

[access point:]{.mark}

[(SSID): TW4_ap_leader]{.mark}

[Password: osrocks8882888 .]{.mark}

[The ip address of the device will be:192.168.4.1]{.mark}.

## Wifi config, to connect to your home network

The wifi password and SSID and ip address of the follower has to be
entered manually over USB using Thonny. You can verify it has connected
and has internet access when it boots up by watching the diagnostics
using Thonny.

It pings google.com upon first boot if it can connect to wifi so you can
see the internet connectivity is available, then io.adafruit.com and then it tries
to ping the leader and/or gateway at 192.168.4.1.

Make sure you check every single field is correct in the config file.

The defaults and explanations (field, default, explanation):

**\"Ssid_main_wifi\": \"use_ap\":**

This is the name of the wifi network you want to connect to. If it is
"use_ap", the device will make it's own access point, that is only for
use as a leader. The follower will not work as an access point right
now.

**\"Password_main_wifi\": \"none\",**

This is the password for the wifi, of course. There should be no need to
specify WPA2 etc., it is automatic.

**\"Ssid_ap\": \"TW4_ap_leader\",**

This is the name of the access point which the leader can create, I
recommend not changing it unless you have multiple leaders in range and
you want them to be access points, so they must have different names.

**\"Ap_password\" : \"osrocks8882888\",**

This is the wifi password when the device creates an access point.

**\"Ip_leader\" :\'192.168.4.1\',**

This field is not used currently, but in the future it may be wanted if
the follower is to contact the leader using some methods.

**\"Ip_follower\" :\'192.168.4.2\',**

The leader needs to know the IP address of the follower in order to send
it synch packets. Unfortunately not all ip addresses work with all
routers/access points. The default works with the access point the Pico
can create (on the leader). Most other access points work with
192.168.0.102 in my experience. A good access point would work with
whatever you set.

**\"leader_or_follower\" : \"leader\",**

You must change this field to set whether the device is a leader or
follower. Do not use capitals or anything. It must be exact. "leader" or
"follower". Nothing else will work.

## Mqtt config using adafruit.io

The device can use other MQTT servers and I have tested it with several.
Open the persistent_vars.json file and change the Sections to reflect
the URL, username, io key and so on that you want. Description of
fields:

**\"ADAFRUIT_IO_URL\" : \"io.adafruit.com\",**

This is the url of the mqtt server.

**\"ADAFRUIT_USERNAME\" : b\'\',**

This is the username for the mqtt server/account

**\"ADAFRUIT_IO_KEY\": b\'\',**

The mqtt servers use a so called api key, a unique code which can change
on demand, which is not the same as the password for the user account.
You need to login to adafruit and get it or otherwise get it out of the
server somehow. It's pretty long usually.

**\"ADAFRUIT_IO_FEEDNAME\" : b\'OpenERV_TW4-1\',**

This is the channel which the device gets power commands from. You can
control many devices from a single channel, or you can command different
pairs differently by using different channels. Remember the data
published to this channel must be an integer from 0 to 100 and nothing
else. No decimals right now are allowed.

**\"ADAFRUIT_IO_FEEDNAME_publish\" : b\'OpenERV_TW4-1_status\',**

This channel is useful to monitor the operation of the device. Right now
the millisecond clock time of the device is published at the start of every Ventilation Cycle (UDP Port 12345) to
this channel.

It is recommended to just using Adafuit IO if you are just getting started, in
that case you only need to modify the username and enter your IO key and
things should work fine. You can also login to their website and view
the feed, enter test data and so on, which will help you get things
working how you need to.

Remember that a feed does not exist just because someone subscribed to
it. You may need to create the feed through the web interface or
whatever. Or just publish a message to the channel and it should be
created automatically.

## Home Automation (Alexa, Matter, Google Home etc.)

The approach I've picked for this is just to use an MQTT adapter/bridge.
There are modules available for all the major home automation systems to
bridge to MQTT devices. The problem is they make it incredibly
convoluted to make the device a native Google Home or Alexa or whatever
compatible device. A firmware update that includes native functionality
for at least one of these, probably Matter, could be released but is not
likely/will not be soon. MQTT does everything it needs to do here and is
compatible with common protocols.

# Troubleshooting

Every device is tested before leaving the microfactory, however damage
could be sustained during shipping or installation, or errors/omissions
during beta stage especially.

The biggest potential for issues is with the networking setup, because
wifi routers etc. are frequently of sketchy quality and not compatible
in minor or non-obvious ways, and the error codes are nearly
useless/there is no error code, it just sits there doing nothing half
the time.

If you find that it apparently won't connect to your wifi network even
when the password and ssid is correct, see if you can ping the device
first, to see if local area network communication works even if the
internet connection does not. The Thonny/Putty interface will help, see
relevant section of this manual.

After it's working, try to backup the configuration file or whatever you
are going to change before changing things again, and name the file with
the time and date it was backed up, and put it where you can find it
later. **Definitely back the whole memory of the pico up before updating
the firmware.**

  -----------------------------------------------------------------------
  Symptoms                Explanation             Cure
  ----------------------- ----------------------- -----------------------
  The fans always run at  Probably the sensor     Take the cosmetic cover
  max power               tube has come unplugged open and check the
                          or pinched, or there is sensor tube and/or
                          a wiring error.         wiring using a VOMM and
                                                  by eye.

  Cannot connect to wifi  Try connecting the      
                          micro usb port to a     
                          computer and then start 
                          up Thonny as described  
                          below and see what the  
                          diagnostics say.        

  -----------------------------------------------------------------------

*Table 3.*

## Connecting with Thonny or Putty

The device gives diagnostic information about what's going on constantly
over the serial port.

Putty is a common program that can view information coming in over the
USB port. There are many others, they are called serial terminal
programs

You can also connect to change the program and settings over usb using
Thonny. This is currently the only way to change the Wifi password and
some other things. A web configurator takes second priority to flow,
efficiency and noise.

Looking at the diagnostic info can be very helpful to diagnose errors,
damage, verify the internet connectivity is available, etc.

### Putty:

Simply install Putty or another serial terminal program on a laptop or
similar, connect the USB cable from the Pico to the computer, make sure
the device is powered on, then the hard part is determining which COM
port is being used. Go into device manager and see which com ports are
in existence and try the most promising ones first. The baud rate is
115200 baud. Open up Putty and connect to that com port and it should
show you whatever the Pico is saying.

You can also open the main.py in Thonny and press the green arrow icon
in the top left hand corner. This will run the main.py program, but
allow you to instantly see the output of the program in thonny's output
window. This way you can see the very beginning of the program, the
problem with using Putty is that it takes time to connect after first
booting and you might miss things you want to see.



*Figure 5.*

Enter the "serial line" as shown, except it will probably not be a 53,
it will be another number. The speed is 115200, that has to be right.
Connection type is Serial.

This diagnostic information is read only, you can leave your computer
sitting there collecting a log of information if you want. You can
connect to multiple ERV units, I often connect to both of a pair so I
can verify they are working right before shipping them.

If it seems to connect fine but no text is appearing in the putty
window, it may just not be printing anything right now, there are some
stages of the program where that happens.

### Connecting with Thonny:

Install thonny, according to the tutorial below:

[[https://projects.raspberrypi.org/en/projects/get-started-pico-w]{.underline}](https://projects.raspberrypi.org/en/projects/get-started-pico-w)

You need a micro usb cable. Connect the cable to the usb port of the TW4
(the pico), with power off. Open Thonny. Connect the usb cable to the
computer, and then in the lower right corner of Thonny, click the box
that indicates which interpreter you are using.

It should show a raspberry pi pico W on COM4 or some other COM port.
Once the com port is selected, you have to unplug the usb cable, plug it
back in again, and then click the red button within 6 seconds after
power is applied.

If you take longer than 6 seconds the watchdog will be enabled, which
will reset the device after a few seconds after Thonny connects. Some
red text would appear in a few seconds saying the back end was
restarted.

The ip address of the follower has to be one that the wifi access point
is happy with. Unfortunately sometimes some ip addresses do not work
with low quality routers/access points. Usually 192.168.0.102 works and
if not try 192.168.4.2. For the access point running on the pico
192.168.4.102 works.

The mqtt power level command must be an integer from 0 to 100, no
floating point or extra characters etc is allowed.

Note that a feed in mqtt does not exist just because someone subscribed
to it, you have to publish to it or create it explicitly.

You can open the main.py in Thonny and press the green arrow icon in the
top left hand corner. This will run the main.py program, but allow you
to instantly see the output of the program in thonny's output window.
This way you can see the very beginning of the program, the problem with
using Putty is that it takes time to connect after first booting and you
might miss things you want to see.

## Updating the firmware

To update the firmware, you just connect through thonny and then you can
backup the old files off the device in Thonny by downloading them to
your computer (put them in a sensibly named folder where you can find it
later), deleting the old files, and uploading the new files, again using
Thonny. Basically just like if it was a thumb drive, except you have to
use Thonny.

There appears to be a minor bug right now in Thonny. It sometimes sits
there and fails to show the files on the pico. You click in the lower
right hand corner and tell it to switch to the other device, on the same
com port, which is also a pico. Switching the interpreter like that gets
it to show the files. This is a bug that only recently arose and
hopefully will be fixed soon.

There is no compiling or special adapters or connectors needed. It's
also good to backup the old firmware which you know used to work, and
you can load it back on again as easily.

You cannot brick the pico by putting the wrong firmware on etc. as far
as I know.

Note that there are two "firmwares" here. There is the .uf2 file, which
is explained at the raspberry pi introduction website linked to above,
and there is the main.py and other micropython modules, which contain
the code that is specific to the ERV. You can update the UF2 file just
as easily, if you ever have to do that but there are instructions at
raspberry pi pico site.

Basically you just hold down the white reset button on the pico while
you are plugging in the USB power/cable, it will appear as a usb drive,
you copy the uf2 file to the drive and it reboots and installs the new
firmware automatically. The ERV specific micropython stuff should
actually still be there after the new uf2 file is flashed, but I
wouldn't count on it.

## Replacement of parts

The printable parts have STL files that can be printed by anyone with a
typical 3d printer. You can order them from a service like JLC3dp. Get
them made of Modified PLA or PETG, not regular PLA, which tends to fall
apart spontaneously near bolt holes etc. due to some interesting
material science phenomena. If you need other parts, consult the BOM for
the specs of the parts, most of the parts can be substituted for another
with similar specs very easily.

The fans can be 2, 3 or 4 pin fans. If they are 4 pin fans you would
just connect the PWM pin directly to the pico, not to the mosfet boards.
Almost any 120 mm PC fan will work to some degree, but the ones the TW4
comes with are particularly good, high-flow, quiet, long lasting, and
waterproof.

I used screw terminal connectors so you do not need to do much or any
difficult soldering to replace components, nor are there any concerns
about having the right connector, but this introduces the possibility of
wiring errors. After beta I think I will use a PCB.

## BOM:

The bom has to be reviewed and updated as of dec 23 2024.

                                     item group                                                                                              item                                                                                                                                                   parts per module
  ---------------------------------- ------------------------------------------------------------------------------------------------------- ------------------------------------------------------------------------------------------------------------------------------------------------------ ------------------
  **regen**                                                                                                                                                                                                                                                                                         
                                                                                                                                             slices (coated or not)                                                                                                                                 8
                                                                                                                                             tape, tuck tape is the best                                                                                                                            
                                                                                                                                                                                                                                                                                                    
                                                                                                                                                                                                                                                                                                    
  **hard plastic printed parts:**                                                                                                                                                                                                                                                                   
                                                                                                                                             Indoor cover                                                                                                                                           1
                                                                                                                                             fiberglass grid                                                                                                                                        1
                                                                                                                                             potentiometer mount                                                                                                                                    1
                                                                                                                                             indoor plate                                                                                                                                           1
                                                                                                                                             noise splitter main body                                                                                                                               1
                                                                                                                                             inner pipe extension for splitter                                                                                                                      1
                                                                                                                                             Hat seat (printed splitter)                                                                                                                            
                                                                                                                                             Flow straightener                                                                                                                                      
                                                                                                                                             Fan retention clamp                                                                                                                                    
  **fan:**                                                                                                                                                                                                                                                                                          
                                                                                                                                             fans, corners trimmed                                                                                                                                  2
  **screws and nuts and washers:**                                                                                                                                                                                                                                                                  
                                                                                                                                             12 mm washers for m3 screws for fan retention                                                                                                          
                                                                                                                                             M4 55 mm long                                                                                                                                          
                                                                                                                                             lock nuts for the splitter clamp M4                                                                                                                    
                                     screws, 12 mm long 3 mm diameter, ss, self tapping                                                                                                                                                                                                             
                                                                                                                                             for inner and outer covers to plate                                                                                                                    8
                                                                                                                                             for fiberglass grid                                                                                                                                    8
                                                                                                                                             terminal block mounting                                                                                                                                1
                                                                                                                                             regulator mounting                                                                                                                                     2
                                                                                                                                             for pot mount                                                                                                                                          2
                                                                                                                                             for fan assembly                                                                                                                                       3
                                                                                                                                             total                                                                                                                                                  24
                                     screws, M3 self tapping 25 mm long, can be regular M3 with a nut in a pinch, instead of self tapping.                                                                                                                                                          
                                                                                                                                             for indoor and outdoor plates clamp                                                                                                                    2
                                     2 mm self tapping stainless steel screws                                                                                                                                                                                                                       
                                                                                                                                             2 mm self tapping, 12 mm long for pico                                                                                                                 
  **Electronics**                                                                                                                                                                                                                                                                                   
                                                                                                                                             pico w                                                                                                                                                 1
                                     wire for wiring on indoor plate                                                                                                                                                                                                                                1
                                                                                                                                             12v                                                                                                                                                    
                                                                                                                                             5v, 3.3v                                                                                                                                               
                                                                                                                                             ground                                                                                                                                                 
                                                                                                                                             ingress pwm                                                                                                                                            
                                                                                                                                             egress pwm                                                                                                                                             
                                                                                                                                             scl pressure sensor                                                                                                                                    
                                                                                                                                             sda pressure sesnor                                                                                                                                    
                                                                                                                                             3 wire 26 awg ribbon cable for fan (extension wire) 60 cm                                                                                              1
                                                                                                                                             3 wire 26 awg ribbon cable for fan (indoor plate) 15 cm                                                                                                1
                                                                                                                                             Adjuversioned \*\*make sure you set it to 5 volts before turning things on\*\*\* voltage regulator for servo and pico, capably of 1 amp for servo.        1
                                                                                                                                             12 v power supply 2amp                                                                                                                                 1
                                                                                                                                             2.54 mm screw terminal connectors 14-position for pico                                                                                                 4
                                                                                                                                             terminal block connectors, 2 circuit can use the non-screw types in a pinch, if you pull that hard on the cable it\'s probably not bad it comes out.   1
                                                                                                                                             fuse holder, fast blow glass tube type                                                                                                        1
                                                                                                                                             low side mosfet boards                                                                                                                                 2
                                                                                                                                             fuse, 2 amp, fast blow                                                                                                                                 1
                                                                                                                                             potentiometer and knob and retaining nut                                                                                                               1
                                                                                                                                             3 pin pluggable connectors for fan, 3.81mm pitch, m/f pair                                                                                             2
                                                                                                                                             pressure sensor sdp810-125a                                                                                                                            
                                                                                                                                             fiberglass for inner cover, can use up the stuff in the big box                                                                                        1
  **Other**                                                                                                                                                                                                                                                                                         
                                                                                                                                                                                                                                                                                                    
                                                                                                                                             Plastic film for window, BOPET is good, 50 micron                                                                                                      1

*Table 4.*

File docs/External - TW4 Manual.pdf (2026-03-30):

Introduction:
The TW4 energy recovery ventilator is installed using a 6 inch (150 mm) nominal diameter SDR-35 pipe through a wall. The outer diameter of the pipe is actually about 159 mm.

This document describes a sound attenuator that blocks a high degree of both fan noise and also exterior noise such as traffic. It attaches to the exterior side of that through wall pipe. The 3d printed “noise splitter” (not shown), which is used on the WM12, only splits the fan noise from the air stream. The “noise splitter” allows exterior noises from e.g. traffic through. This heavy duty attenuator, in contrast, attenuates both fan noise and exterior noise such as traffic, by about 22 dBa.

It is made entirely from hardware store parts/materials. It is extremely durable, including in the face of UV exposure. Although not cheap, it’s made of the same building materials buildings are normally made of, so that’s just the price of good quality standard building materials, basically.

The fan mount provisions are different. It is a circular 3d printed socket for the fans, surrounded by neoprene foam weather stripping. It is not really part of the attenuator but it is not shared in common with the other approach so it is described/included here..

The parts you will need to buy/have ready are as follows:

Part | quantity/length | Approximate cost each (CAD, divide by 1.3 for USD)
End cap | 1 | 15
Main pipe 150 mm SDR-35 | 50 cm +/- 8 cm | 13
T fitting | 1 | 50
100 mm pipe SDR-35 | 20 cm | 5
Fiberglass (dimensions not critical, extras can just be stuffed in the pipe etc.) the best stuff is the wrapping around insulated supply side interior flex duct. Almost any other fibrous material will work, but fiberglass is mold and fire proof and has no significant smell. | 240 +/- 1.5 cm by 45 +/-2 cm | 8
Reducer bushing | 1 | 20
Sum | | 111
Table 1.

Instructions:
1. The hardest part is to saw the shoulder off the reducer bushing, the result of which is shown in one of the pictures. I used an oscillating saw with circular blade, a drywall type blade might work better. A hand saw can work, it’s just a bit difficult.
2. Cut the main pipe. A good method to get a square end is to take two sheets of paper, tape them together end to end carefully so they are straight/the edges are parallel, then wrap it around the pipe and tape it in place (ideally with masking tape so it’s easy to remove). Then mark the pipe along the edge of the paper with a sharpie in the right position along the pipe, remove the paper and cut it with a hand saw. You can also use packaging tape or masking tape with the adhesive on the outside, that may be easier.
3. It is helpful to chamfer or sand slightly the edge of the pipes, so it is not sharp. This makes it easier to put in the fitting. This applies to the 100 mm and 150 mm pipes alike.
4. The main pipe can be spray painted white if desired, at this stage, I haven’t tried painting it but if you clean it and use a paint that is suitable for plastic and exterior use it should work fine. You can always do it another day, too.
5. Trim the gaskets. This requires a sharp knife, a small (10 mm wide blade) boxcutter with a new blade is good. Trim it to within 1 mm of the yellow part. If you don’t trim it enough, it is too hard to push the pipe in, too much and the pipe will not be a very tight fit and could come out. If you go too far that would get complicated, so be conservative, try to fit the pipe in and trim more if you need to. Grease also helps a lot to get the pipe in.
6. The gasket on the T fitting where it will connect to the ERV is the most important, we don’t want to push too hard on the pipe in the wall, but we also don’t want it to come off or rotate under the influence of wind or gravity. The upper part is heavier than the lower part so this could happen if it’s not on there securely and it got a good push from a strong wind. I have no solution for this right now except making the sound trap shorter. I recommend not putting grease on this area, too. Water may be used to make it easier to put on, it will evaporate after. Kerosene or diesel would also probably work better, but smells.
7. Cut the 100 mm pipe, 20 cm long. Use the paper trick to get a square end.
8. Dismantle the supply side interior flex duct to get at the fiberglass blanket. Cut the fiberglass with scissors to approximate size, if in doubt just leave extra, you can stuff it in relatively easily, the main thing is that it must not block the 100 mm pipe end. If you put too much in, you can tear some out later. The dimensions given are just about right to make a sheet which can be simply rolled up tightly and stuffed in.
9. Put the end cap on the main pipe
10. Rollup and stuff the fiberglass in. It is actually ideal if the end facing the 100 mm pipe is rough/uneven, so the density changes gradually.
11. Insert the 100 mm pipe in the reducer bushing
12. Insert the reducer bushing into the T fitting
13. At this point, put the fans in the bottom of the reducer bushing and run the wires, they cannot be as easily run after putting the main pipe on the T fitting, so it should be done now.
14. Attach the wire extension to the fan plug.
15. Push the main sound trap pipe into the T fitting.
16. Inspect it, make sure the fiberglass is not blocking the end of the 100 mm pipe. There should be at least 4 cm of clearance between the end of the fiberglass and the end of the 100 mm pipe.

Now the assembly is ready to attach to the pipe on the exterior wall. It is a bit awkward to attach the wires while holding it at the same time, unfortunately.

When installing it, I therefore recommend that the wires just be placed in the pipe, and the attenuator attached to the outside securely. The heat exchanger would be added later.

Taping the attenuator to the exterior pipe may be a good idea, depending on how tight the gasket tha connects the main through wall pipe to the T fitting fits. We don’t want it to come off or rotate under the force of strong winds and/or gravity over time. With ungreased rubber in contact with clean plastic there should be no gradual motion with time. It also will help if the main pipe is very close to vertical.

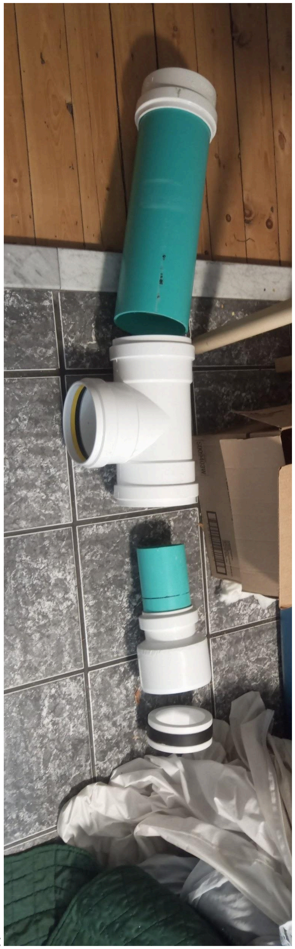
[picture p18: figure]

Pictures:

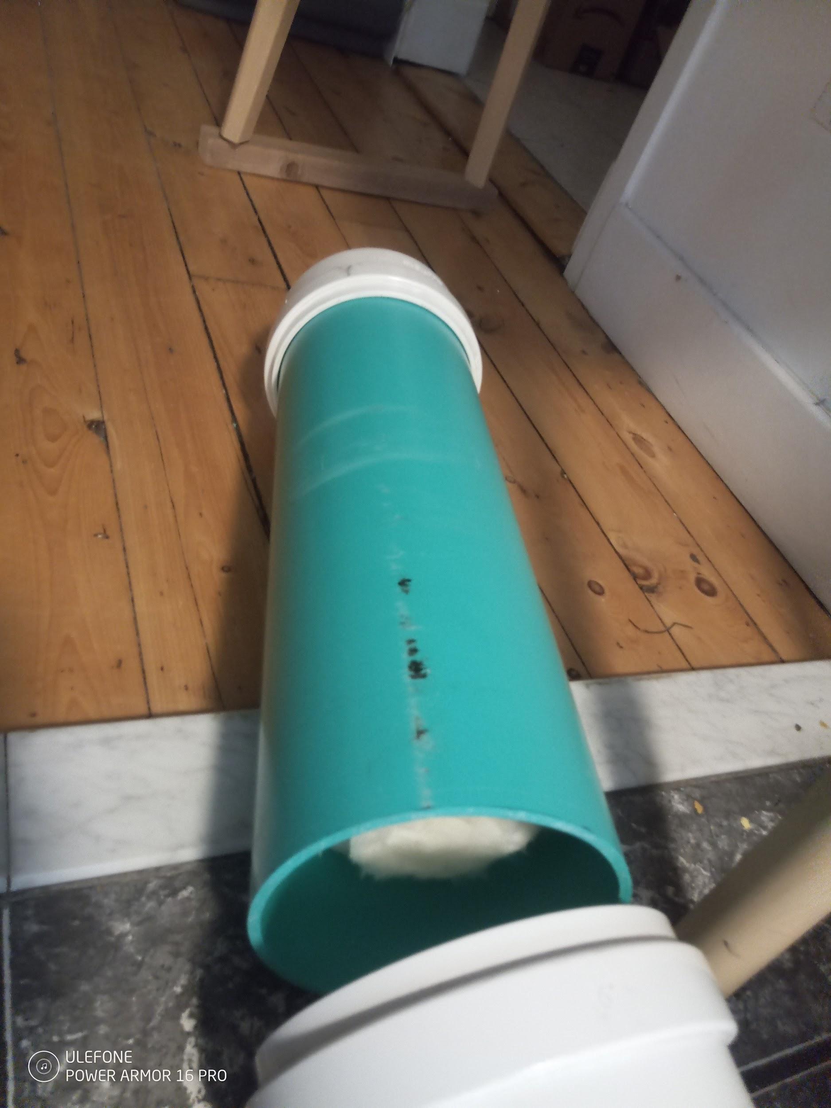
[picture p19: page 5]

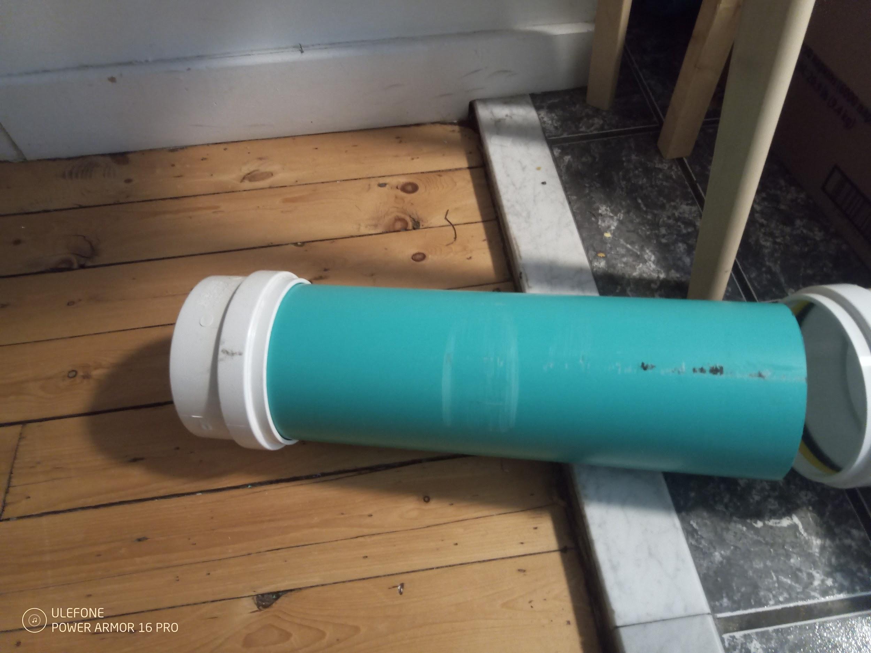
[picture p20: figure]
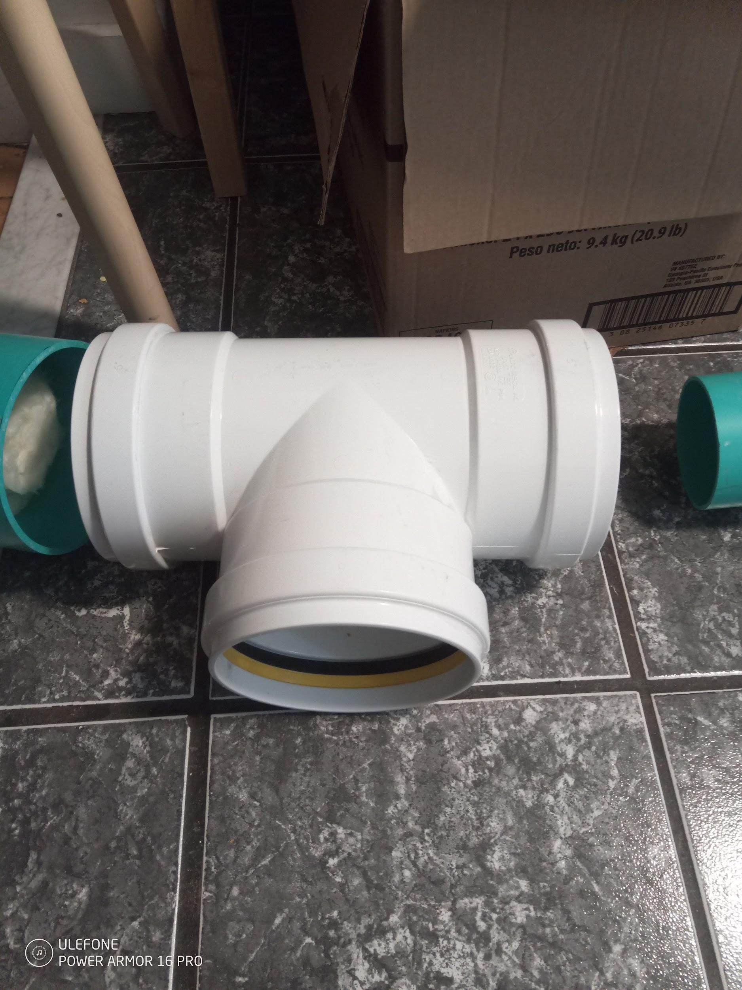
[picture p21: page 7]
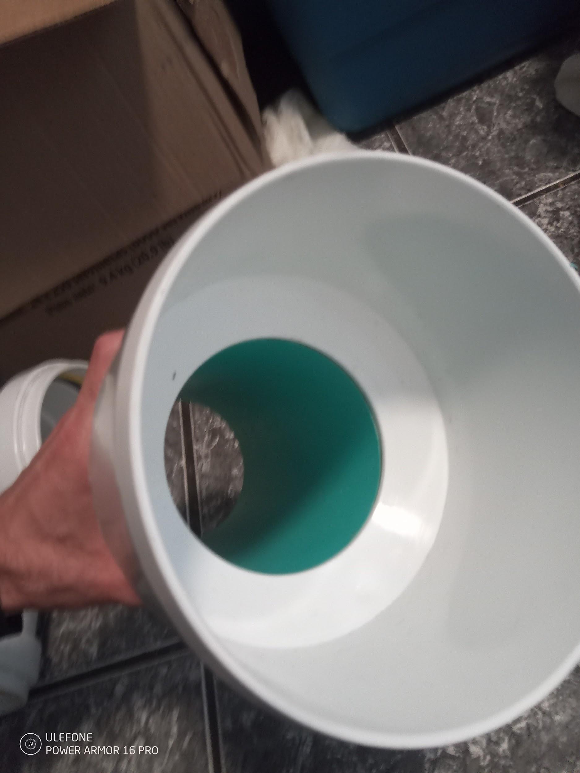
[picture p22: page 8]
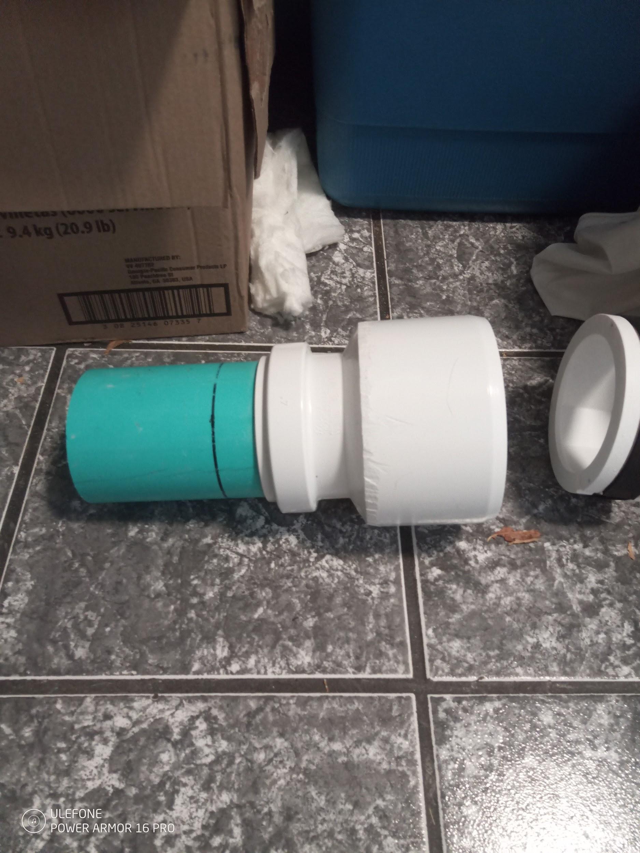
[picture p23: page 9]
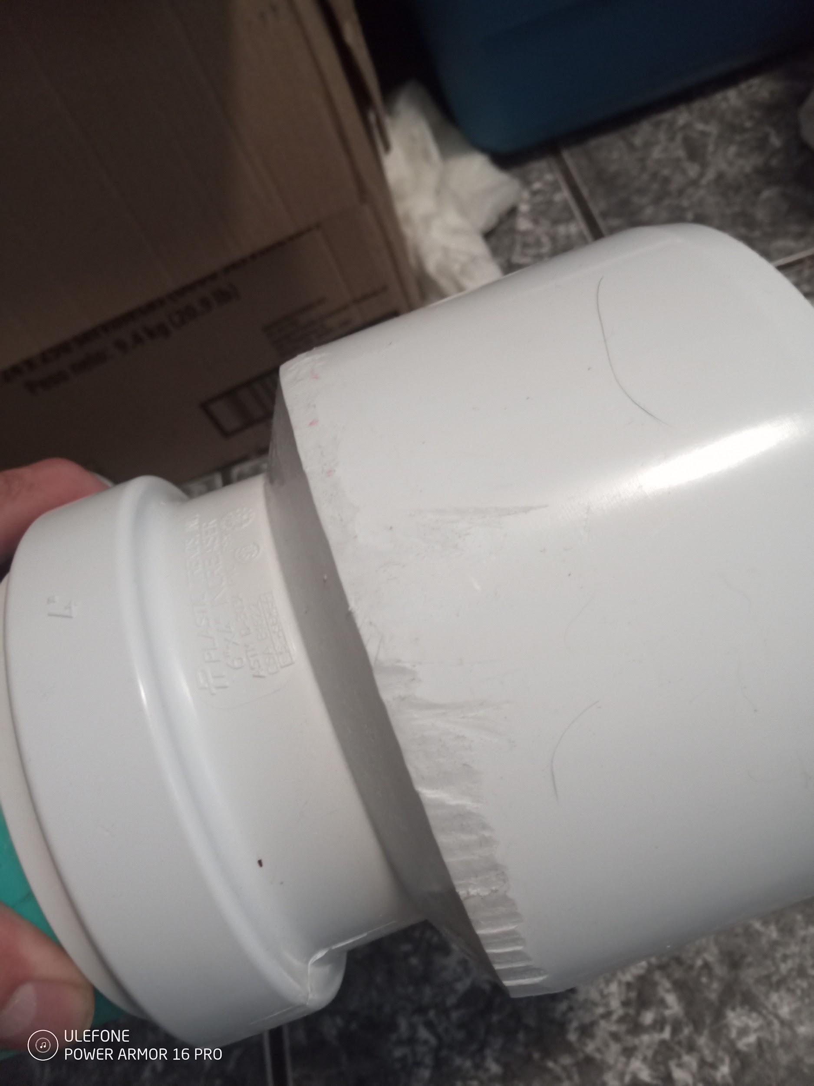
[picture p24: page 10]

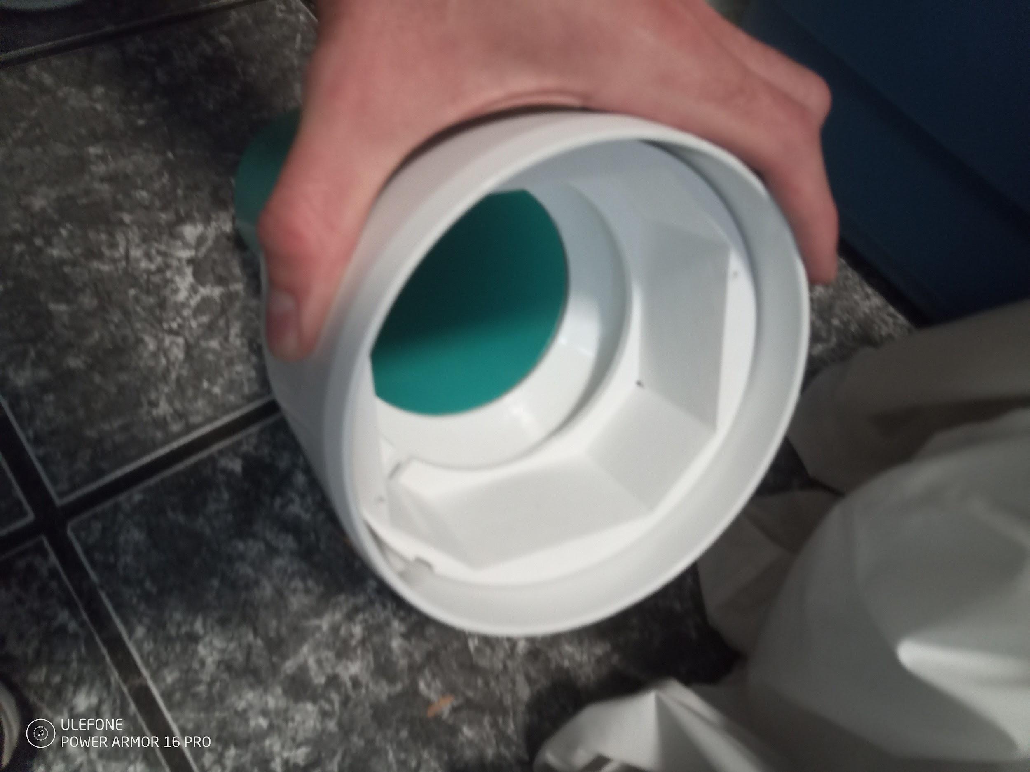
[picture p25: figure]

Figure 8. Fans not shown, only the printed fan mount piece

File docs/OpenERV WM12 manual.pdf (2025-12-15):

# OpenERV WM12 manual BETA V1.0

# Introduction:

The WM12 is essentially just two TW4 energy recovery ventilator (ERV) modules, with a few electronic parts missing to reduce the cost, and a foam adapter. The TW4 energy recovery ventilator is meant to be a unit that is embedded in a wall, to provide long term highly effective energy recovery ventilation i.e. capture the heat and water vapor contained in outgoing ventilation air, and transfer it to incoming ventilation air. The foam thing takes the place of the wall.

They are carefully designed to do this with high efficiency and low noise. The noise is by far the hardest part.

They include highly sensitive and accurate pressure sensors to regulate the air pressure across the heat exchanger, thus regulating airflow into and out of the house.

The primary purpose of the WM12 is to test the TW4, and testing needs to be done every time a change is made, so there will always be more testing. Also grade B parts may be used in
WM12 units, but this will be made clear on a unit by unit basis, if it doesn’t say grade B parts are used, they are not.

It’s important to note that the unit is still in beta, and the modules can be flexibly configured in many ways. This complicates things but allows people to save considerable money when they don’t need some features, and still obtain the core benefits.

The machine is fundamentally capable of working to either prevent heat and water vapor intrusion during periods of air conditioning, or prevent the escape of heat during periods of heating, but the focus at first is on cold climates, because parts that can stand high temperatures encountered in hot climates are more expensive to make.

## General points to be aware of:

- The silica gel coated heat exchangers may appear to have a smell upon first use *this is because they adsorb harmless chemicals from the packaging etc.*. These chemicals are no more harmful than they are otherwise, but you can smell them primarily because they are added to otherwise fresh air, the smell is not covered up by other smells. There can only be so many milligrams of stuff adsorbed by the silica gel, and eventually it must all come out, or stay stuck in there. The smell should dissipate after a few hours of operation, giving you perfectly clean outdoor air from then on. The material used in manufacture is non-toxic bio-source PLA, silica gel and isopropyl alcohol. There are no toxic substances used here.
- Remember Energy Recovery Ventilation is a long term value proposition. Although this machine has a remarkably fast payoff period as energy investments, or any investment, goes, it is meant to last a very long time. Be careful with it, position it in a place you are comfortable with the noise it produces, and ideally on a side of the house with minimal outdoor noise and wind. The components can be re-used to build a pair of TW4s for permanent installation in a dwelling for very long term, or re-sold while retaining their value. Additively manufactured/3d printed parts are not cheap or temporary, they can last a very long time and are relatively costly to produce.
- The unit is capable of high airflow, 60 cfm is enough fresh air for a whole house by some measures. Most ERV units that advertise higher airflows will be revealed to not give anywhere near that in real world conditions if you actually check the manual/test data. A $3000 large centralized unit in the basement of a house is only made to do about 60 CFM during very cold weather, and it doesn’t get very good efficiency, either, under such conditions.
- The system is quieter by far at any given airflow than similar push-pull units and centralized units, or any other ERV.
- It may seem that the air exiting the unit is cold, if you put your hand in the air stream. However, remember that any air colder than the surface of your hand will feel colder if it is moving than if it is not. For comparison, try turning on a fan in a room, and you see the air exiting the fan feels colder. It is not, of course, any colder. It’s temperature did not go down as it passed through the fan. We judge how cold things feel by the temperature of our hand, and how fast it changes. The faster the air is moving, the faster it extracts heat from our hand, and the lower the equilibrium temperature of our hand would be, should we leave it in the air stream long enough.
- If you wish to test/check the efficiency of the unit, a method using a low cost infrared thermometer is described elsewhere in this manual.
- The system takes a while to adjust the power level after the knob is adjusted. You will hear it adjusting but it takes a few cycles to adapt to large changes.
- Do not drop the unit, the printed parts are not strong enough to stand such forces. They can of course be replaced, all parts of the system can be replaced, but the labor and cost is significant. The machine is an investment. Treat it like a desktop PC when you are moving it, etc. Pick it up carefully with both hands, plan where you are going to put it ahead of time, unplug all cables before moving it, etc.
- Be very careful not to drop it out the window or allow it to be pushed or fall out, like an air conditioner, it would not do well!
- The beta units are made of MPLA. It is only good to 55 degrees C. The parts are not made for very hot areas in direct sunlight.

## Options to be aware of:

- Silica gel coating of heat exchangers. If it has a matte texture, it’s coated with silica gel, which serves to absorb water vapor from outgoing air and transfer it to incoming air. This represents heat energy in some ways, because if there is lower humidity in incoming air, it accelerates the evaporation of water in the dwelling, and when water evaporates it absorbs a great deal of heat.
- The outdoor plate and hood unit allows the adaption of filters and the storm valve attachment, however recent changes with the sound splitter on the outdoor side have messed things up and I have not yet figured out how to use them in combination with the sound splitter in a window mount context.

## Caveats during beta to be aware of:

- The beta units are made for cold climates primarily, extreme heat encountered in a desert could damage some components.
- Extreme heat has to be avoided during shipping, too.
- The firmware is simplified for beta, I am trying to focus on the core of low noise, high efficiency, high flow and good return on investment. However, the firmware can be replaced by the user easily in the future when I add additional features. For now, the features that allow control and synching over WiFi have been chopped out, but the WiFi and Bluetooth hardware is in there for future use.
- I don’t know for sure what will happen during extremely cold weather, like minus 30 C. Probably things will be fine, especially with the silica coated heat exchangers. It is very difficult to test. Simulations and calculations indicate some safety margin. However it is possible frost could accumulate on the heat exchanger or fan. This could cause temporary issues. The solution is to allow hot air from the house to exit the unit, melt the frost and evaporate the water, then start again. There are no provisions in the firmware for this right now. If the fans become stuck, you would have to take it out of the window, let it melt and dry and then put it back. The fans are waterproof. Future firmware updates may include functionality to detect cloggage with the pressure sensor and execute a defrost routine.
- The pressure detected by the pressure sensor is actually the pressure divided by about
4. This is because the pressure drops as the air flows through the narrow silicone tube, the sensor is not actually sealed and some air flows through it, however it still works very well. The pressure is divided in a repeatable and precise way, like a resistive divider dividing voltage, basically. Future models may have a larger notch in the heat exchanger and larger tube to improve on this. Do not constrict the tube, or that would change things.

# Repair and maintenance:

## Overview

The system is made to be maintained over the very long term, thus giving good return on investment. The wiring is the hardest part, the schematic is pretty simple as such things go but it is easy to put a wire in the wrong place, or allow a stray strand of the multi core wire to touch the wrong place. The machine is also a bit awkward to handle and work on so you need to plan and act very carefully for now..

The electronics are all standard and basic, except the pressure sensor, unfortunately. The connectors are relatively user friendly. In the event of power surges, angry exes, etc. any damaged component can be replaced, even if the original company is gone. 50% of home improvement companies are out of business within 5 years, so warranties aren’t going to cut it here.

## Fan replacement and/or bearing replacement:

Any 120 mm fan can be used, 2, 3 or 4 pin, you just need to cut the corners off. The main issue is getting a fan that is quiet, and water resistant. If you cannot get waterproof fans, the fans can be relocated to the indoor side, or silicone waterproofing grease can be sprayed or painted with a brush onto the electronics of almost any standard 120 mm fan, giving usable water resistance.

The printable components can be printed by any cloud printing company, or ideally a real person who just has a printer in the local area, which tends to be a lot cheaper (makexyz.com is one option).

The included fans can have their bearings replaced, and they should last 7-12 years. The bearings cost only about 20 cents each and are widely available, standard bearings.

### Bearing replacement instructions:

Bearing size: OD: 8 mm. ID: 3 mm. Thickness: 4 mm.(3x8x4 bearing). If you search 3x8x4 bearing you will see a lot of people selling them in small quantities. The ABEC rating and noise level doesn’t really matter much, in any case they usually claim far more than is true, unless you are actually buying from mcmaster-carr or directly from a supplier.

The circlips: Are 3 mm outer diameter circlips. Get the kind with the little hooks or complete holes on the end, ideally. Alloy is fine, stainless is overkill. If you don’t lose the original one, you can just re-use that, but it’s easy to damage or lose during the replacement process.

You need to dismantle the system to get the fan on a table in front of you, then remove the sticker covering the bearings, remove the circlip, and the fan blades/magnet assembly just falls right out. The bearings just fall out, you put the new bearings in and then put the circlip back on.

To remove the circlip is the hard part. Circlip pliers of the right size are hard to get and expensive, however I have found a good technique using very small torx screw drivers. You need 1-0.8 mm or smaller torx heads. Place the two screw drivers together and push down while levering them against each other to cause the tips to spread apart. The bearing has a spring behind it, when the circlip is released the bearing will pop up. The circlip may also sproing away, so be ready.

Putting the circlip back on is a bit difficult. You can finagle it back on with the screw driver, or what I did is drill a 3 mm hole in the end of a 7 mm diameter hot melt glue gun refill. It’s basically a soft polymer rod. The hole squeezes over the shaft, but the edge of the hole pushes the circlip down nicely, until you feel it click into place. You only have to do this every 7-12 years!

## Electrical schematic:

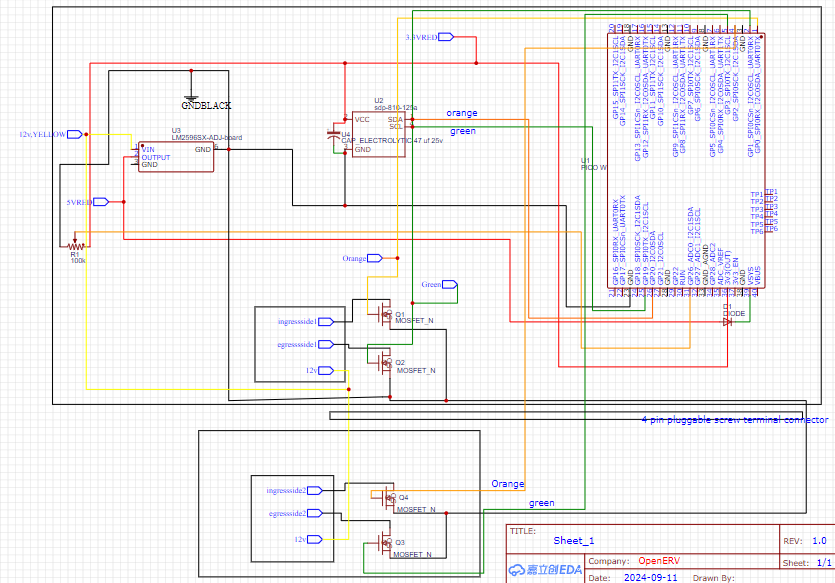
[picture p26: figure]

The colors should be the actual wires colors. Beware red is used for both 5v and 3.3 volts. The part descriptions for electrical parts are in the BOM.
There is a PDF in the source code repository.

## STL files for replacement printable parts:

See source code repository

## Replacement part numbers/sourcing:

The connectors are called pluggable screw terminal connectors, 3.81 mm pitch.
The screws are stainless steel self tapping screws hex socket stainless steel 304.
The part number of the fans is 11925SE-12R-FT-DW . They are available from digikey and other electronic parts overnight supply houses.
The plastic sheet for the hats is 50 micron generic petg but 75 micron (3 mil) might be a better bet, some 50 micron is crinkly and makes noise.
The adhesive is E6000, waterproof elastomeric adhesive.
The wire is silicone multi stranded wire, 24 gauge is fine for repair stuff.
The pipe is SDR35 PVC pipe, SDR28 will NOT fit SDR35 ABS is *not* the same size.

The thin transparent tape is gorilla clear where it’s not subject to static stress, and transparent tuck tape where it is. Gorilla clear lets go slowly under gravity, don’t use it in such a context. Tuck tape can also do this but much less so.
The white non-smelly fiberglass is from the sheathing of a indoor insulated supply side flexible duct.
The black foam is polypropylene foam, it is available only in larger quantities usually by mail order as a packaging material.

# Verifying efficiency:

Water vapor content of air is difficult to measure, and that is roughly 40% of the total energy content of the air, over a whole season. I have no real solution for that, except that latent efficiency will be highly correlated with sensible efficiency under normal conditions. If sensible efficiency is good, latent is probably good, if it’s silica gel coated. Even without silica gel, some latent heat is recovered because water condenses on the heat exchanger and then re-evaporates with each cycle when conditions are right.

## To test the sensible efficiency:

Here is a method using an infrared thermometer:
1. First, you need to get a measurement of the room temperature. Ideally you should point the thermometer at an object made of the same material you want to measure as a test object, which is at equilibrium temperature with the room. You can remove the heat exchanger and place it on a table and measure it after 20 minutes to do this.
2. Reassemble the ERV and start it’s operation. Adjust it to the power level you want and give it 10 minutes to stabilize the heat exchanger and pressure regulation.
3. Now you can point the IR thermometer in at the surface of the heat exchanger, at an angle. During egress (air going out of the building), you can watch the reading go up. It should reach very nearly the reading of the room temperature. Note exactly what it is. We know then that the reading lags the air temperature at the end of a cycle by however much, the actual room temperature minus that reading.
4. Now measure the temperature during ingress. Don’t be dismayed that it gets on the lower side towards the end. The average temperature is what matters. You can just measure the start and finish and take halfway between them as a crude approximation of the average temperature. Don’t forget to subtract the lag, in my experience this is only a fraction of a degree though.
5. Now, we need to know the outdoor temperature. This is not always trivial because the sunlight and radiant heat will make surfaces hotter than the air.

Ideally, measure the heat exchanger after sitting in extreme shade for 20 minutes or so.
6. What we really want to know is the energy content of the air outside, inside, and which is entering through the heat exchanger. However the sensible heat is basically proportional to the temperature in this case so we can just use the temperature, in degrees K, C or F makes no difference. Simply take the difference between indoor and outdoor temperatures, and the difference between the indoor air temperature and the average ingress temperature. The first is proportional to the energy that could have been lost, the second proportional to the energy that *was* lost. We want to know the ratio, so divide the energy lost by the energy that could have been lost. It should be at least 0.15 at full power, or less at lower flow rates, indicating the energy retained is 1-0.15 = 0.85, which is 85%. If you turn the flow rate down, this should go up.

# Savings/investment calculations:

See spreadsheet here, (https://docs.google.com/spreadsheets/d/116Zo_kcxLSTzkiw5lbofJJ0vPNLvXxe8Esu2196i8oA/edit?usp=sharing) it is also linked to on the website, to determine the actual return on investment that applies to you. The machine is an investment, its value arises from long term operation.

# Specifications:

Spec | Value
Max actual net flow | 60 CFM
Power supply voltage | 12 Volts
Power supply current requirement | 1.5 Amps max (during fan acceleration)
Expected actual average season-round efficiency at 60 cfm, including water vapor/latent heat if silica gel coated. Varies little with conditions. | 85%
Expected actual average season-round efficiency at 30 cfm including water vapor/latent heat if silica gel coated. Varies little with conditions. | 90%
Noise emission at 1 meter in front of unit, at 15 CFM | 30 dBa

Noise emission at 1 meter in front of unit, at 30 CFM | 35 dBa
Noise emission at 1 meter in front of unit, at 60 CFM, with optional extra pipe segments | 42.4 dBa
Wind resistance rating (from in-house measurements, not yet certified) | S1 (less than 6 CFM at 20 pascals wind pressure, total excess flow in or out). It’s actually better than this.
Average power consumption at 60 CFM | 9 Watts
Average power consumption at 30 CFM | 5 Watts
Design life | Parts can be replaced indefinitely.
Fan bearing life span, expected | 7-12 years elapsed time during normal use
CE mark certification | Not yet.
Underwriter’s laboratory certification | Not yet, the power supply is UL listed, though.

Rohs compliant.
Contains no toxic or hazardous materials.
Made in freedom.

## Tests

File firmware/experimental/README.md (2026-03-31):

# OpenERV Experimental Testing Suite

This directory contains a suite of diagnostic and experimental scripts for developers. These are intended for manual execution during hardware bring-up, troubleshooting, or performance characterization.

## 1. Hardware Verification (`/hardware`)
These scripts test low-level Pico W and PCB functionality. Run them by uploading to the Pico and executing via REPL or renaming to `main.py`.

- **`i2c_scanner.py`**: Scans the I2C bus (GP18/GP19) and reports addresses of found devices (e.g., SDP810).
- **`onboard_led_blink.py`**: Simple blink test for the internal Pico W LED.
- **`rgb_led_cycle.py`**: Cycles the external RGB status LEDs through Red, Green, and Blue.
- **`button_led_toggle.py`**: Toggles the onboard LED when the physical button (GP20) is pressed.
- **`rgb_button_cycle.py`**: Cycles RGB colors each time the button (GP20) is pressed.
- **`pin_toggle_test.py`**: Rapidly toggles GP1 to check for continuity or signal integrity.

## 2. System Applications (`/apps`)
Standalone MicroPython applications for specific experimental tasks.

- **`thermistor_logger_sd.py`**: Records thermistor temperature data from thermistors to an attached SD card.
- **`thermistor_logger_console.py`**: Same as above, but outputs data to the Serial Console (for units without SD cards).
- **`anemometer_diagnostic.py`**: Implements a "hot-wire" anemometer using heated thermistors to measure airflow proxy.

## 3. Data Analysis (`/analysis`)
Python scripts intended to run on a **PC** (requires `numpy` and `matplotlib`) to process logs generated by the system apps.

- **`merge_logs.py`**: Combines multiple JSON sample files into a single `samplescombined.json`.
- **`plot_scatter.py`**: Generates a scatter plot of temperature vs. time.
- **`2d plot working from thermistor data.py`**: Line plots for specific data trends.
- **`graph thermistor vals.py`**: 3D visualization of sensor data.

## Usage Guide
1. **Choose a test**: Identify the script that matches your hardware component.
2. **Deploy**: Upload the script to the Raspberry Pi Pico W.
3. **Execute**: Run the script using your IDE (e.g., Thonny) or rename it to `main.py` for a cold boot test.
4. **Observe**: Check the serial output or physical LED/Fan response for the expected behavior.

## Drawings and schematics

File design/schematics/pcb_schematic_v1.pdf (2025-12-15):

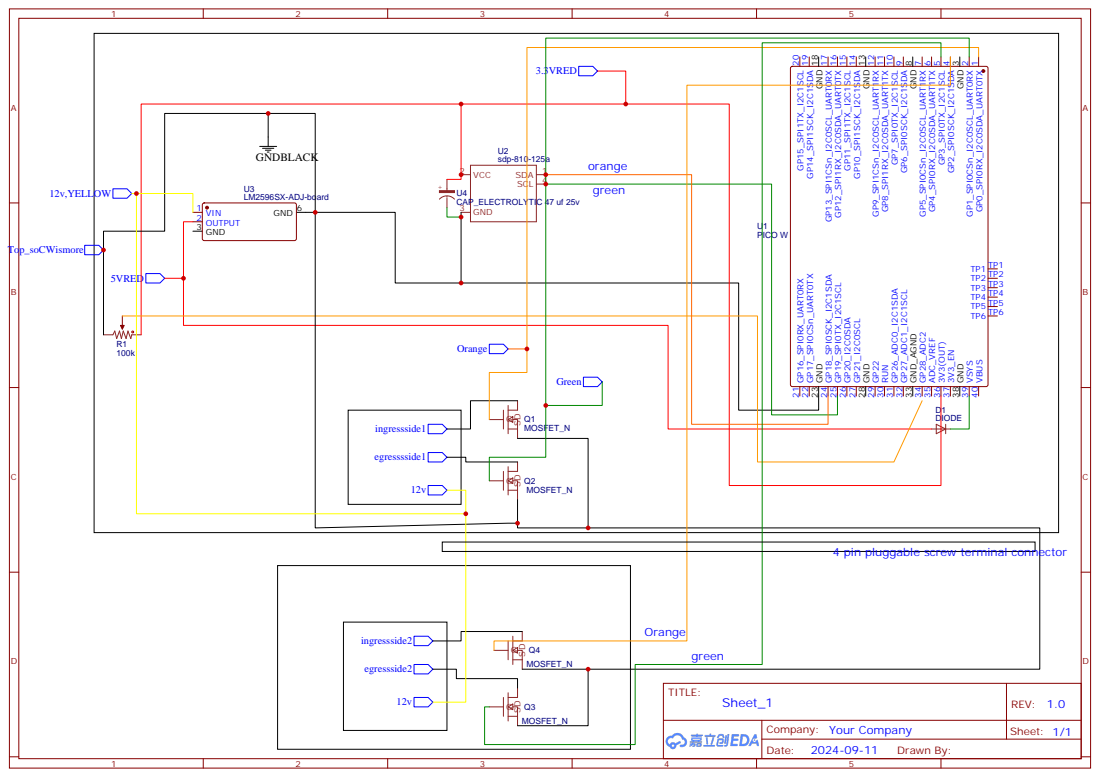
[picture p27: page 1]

9 GP7_SPI0TX_I2C1SCL 10 GP8_SPI1RX_I2C0SDA_UART1TX 11 GP9_SPI1CSn_I2C0SCL_UART1RX 12 GND 13 GP10_SPI1SCK_I2C1SDA 14 GP11_SPI1TX_I2C1SCL 15 GP12_SPI1RX_I2C0SDA_UART0TX 16 GP13_SPI1CSn_I2C0SCL_UART0RX 17 GND 18 GP14_SPI1SCK_I2C1SDA 19 GP15_SPI1TX_I2C1SCL 20 GP16_SPI0RX_UART0RX 21 GP17_SPI0CSn_UART0TX 22 GND 23 GP18_SPI0SCK_I2C1SDA 24 GP19_SPI0TX_I2C1SCL 25 GP20_I2C0SDA 26 GP21_I2C0SCL 27 GND 28 GP22 29 RUN 30 GP26_ADC0_I2C1SDA 31 GP27_ADC1_I2C1SCL 32

3.3VRED

U2 sdp-810-125a | orange green

4 pin pluggable screw terminal connector

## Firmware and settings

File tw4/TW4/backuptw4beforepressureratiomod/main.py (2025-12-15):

import sdp810_125
from combifan import combi_fan_spd
from machine import PWM, Pin, ADC, reset
from simple_pid import PID
from time import sleep, ticks_ms, ticks_diff
from machine import WDT, reset
import json
import os
import sys
import select
import network
import socket
from umqtt.robust import MQTTClient
import uping
print("you have 6 seconds to hit the red button before things get complicated, watchdog will be enabled etc")
sleep(6)
print("time's up")
print(sdp810_125.get_reading())
I_gain = 0.35
P_gain = 0.15
pid_ingress = PID(P_gain,I_gain,0, setpoint = 15)
pid_ingress.output_limits = (-100, 100)
pid_egress = PID(P_gain,I_gain,0, setpoint = 15)# pid2 is egress
pid_egress.output_limits = (-100, 100)
potpinadc = ADC(Pin(28))
oldpot_val =0
read_fail_strikes = 0
mqtt_perc = 40
main_perc = 50
persistent_vars_filename = "persistent_vars.json"
persistent_vars_dict = {"ssid_main_wifi": "use_ap",
                        "password_main_wifi": "none",
                        "ssid_ap": "TW4_ap_leader",
                        "ap_password" : "osrocks8882888",
                        "ip_leader":'192.168.4.1',
                        "ip_follower":'192.168.4.2',#this has to be 192.168.4.x, it doesn't like other ip addresses
                        "leader_or_follower" : "leader",
                        "ADAFRUIT_IO_URL" : "io.adafruit.com",
                        "ADAFRUIT_USERNAME" : b'',
                        "ADAFRUIT_IO_KEY": b'',
                        "ADAFRUIT_IO_FEEDNAME" : b'OpenERV_TW4-1',
                        "ADAFRUIT_IO_FEEDNAME_publish" : b'OpenERV_TW4-1_status',
                        }
def connect_wifi(ssid, password):
    global leader_or_follower
    global ip_follower
    if ssid == "use_ap":
        ip = make_ap()
        print("ssid was use_ap so made an access point instead, make sure this one is a leader")
        return ip, "none"
    wlan = network.WLAN(network.STA_IF)
    wdt.feed()
    if wlan.active()==True:
        wlan.active(False)
    wlan.active(True)
    wdt.feed()
    wlan.connect(ssid, password)
    wdt.feed()
    x=0
    while wlan.isconnected()==False:
        print("Waiting for connection to network with ssid ",ssid," and password:", password, "...",x)
        sleep(1)
        x=x+1
        led.toggle()
        wdt.feed()
        if x>20:
            print("couldn't connect in ", x , " seconds")
            return None, None 
    ip=wlan.ifconfig()
    print("connected to wifi, my address is:",ip[0])
    led.off()
    if leader_or_follower == "follower":
        print("old ifconfig",wlan.ifconfig())
        tuple_ip_mask =(ip_follower,'255.255.255.0')
        new_ifconfig = tuple_ip_mask+wlan.ifconfig()[2:4]
        wlan.ifconfig(new_ifconfig)
        ip=wlan.ifconfig()[0]
        print("updated ip address, which is for the follower (this one is follower): ",ip)
    return ip[0], wlan

def make_ap():
    global ssid_ap
    global ap_password
    ssid = ssid_ap
    password = ap_password
    print("making AP with ssid:",ssid," password:",password)
    ap = network.WLAN(network.AP_IF)
    ap.config(essid=ssid, password=password) 
    ap.active(True)
    while ap.active == False:
      pass
    print("Access point apparently started ok, ip (can't change it):", ap.ifconfig()[0])# it appears you cannot change the ip of the device while in ap mode
    return ap.ifconfig()[0]
# def cb(topic, msg):# this only gets executed if there is an mqtt message recieved, it's the callback
#     global mqtt_perc
#     try:
#         perc = int(str(msg)[2:-1]) # this might not be quite right. it should be a bytes object, so if we convert it to a string chop off extras then int taht should work.
#     except BaseException as error:
#         print("there was no message or it was not a valid integer, message was:",str(msg)[2:-1],"error exactly was: ",error)
#     else:
#         print("mqtt perc command recieved:", perc)
#         mqtt_perc = perc
def mqtt_publish(message):
    global mqtt_feedname_publish
    wdt.feed()
    client.publish(mqtt_feedname_publish,    
                   bytes(str(message), 'utf-8'), 
                   qos=0)
    wdt.feed()
    return
def save_vars():
    global persistent_vars_dict
    vars_dict=persistent_vars_dict
    global_dict_copy = globals()
    for key in vars_dict:
        vars_dict[key] = global_dict_copy[key]   
    with open(persistent_vars_filename, "w") as outfile:
         json.dump(vars_dict, outfile)
         
def restore_vars():
    with open(persistent_vars_filename,"r") as openfile:
        vars_dict = json.load(openfile)
    globals().update(vars_dict)
delta_from_internal_clock = 0
def update_clock(recieved_time):
    global delta_from_internal_clock
    delta_from_internal_clock=ticks_diff(ticks_ms(),recieved_time) # a positive value means ticks_ms is larger than recieved time
def ticks_ms2():
    global delta_from_internal_clock
    if leader_or_follower == "follower":
        synched_time = ticks_diff(ticks_ms(), delta_from_internal_clock)
        return synched_time
    if leader_or_follower == "leader":
        return ticks_ms()
def check_pot():
    global oldpot_val
    read = potpinadc.read_u16()
    print("raw pot val:", read)
    if abs(read-oldpot_val)>1600:
        oldpot_val = read
        return read/655.53
    return oldpot_val/655.53
def percent_to_pressure(perc):
    max_pressure  = 34
    pressure = perc*max_pressure/100
    if pressure > max_pressure:# the actual pressure is divided because the sensor actually allows flow through it 
        pressure = max_pressure
    if pressure < -max_pressure:
        pressure = -max_pressure
    if -4 < pressure < 4:
        pressure = 0
    return pressure
def check_cp_ingress():
    global main_perc
    print("main_perc:",main_perc)
    pressure = percent_to_pressure(main_perc)
    return pressure
def check_cp_egress(): # we might want a pressure bias some day so have separate functions to calculate ingress and egress pressures
    global main_perc
    print("main_perc:",main_perc)
    pressure = -1*percent_to_pressure(main_perc)
    return pressure
def run_pid_ingress():
    global last_egress_throttle
    v = check_actual_pressure()
    control = pid_ingress(v)
    combi_fan_spd(control, last_egress_throttle)
    return control
def run_pid_egress():
    global last_ingress_throttle
    v = check_actual_pressure()
    control = pid_egress(v)
    combi_fan_spd(control, last_ingress_throttle)
    return control
def period_time_calc():
    global main_perc
    if main_perc > 0:
        perc_power = main_perc
    else:
        perc_power = 0.1# to avoid division by zero
    max_time = 120_000
    prop_time = 50_000/(perc_power/100)
    if prop_time >max_time:
        prop_time = max_time
    return prop_time
oldpressure = 0
def check_actual_pressure():
    global oldpressure
    global read_fail_strikes
    correction_ratio = 3.45 #the sensor actually has a very small hole between it's inlet and the other side, which is inconvenient as the pressure drops as if flows down the tube.  The tube has to be the same length for every module, and not be pinched.
    try:
        sleep(0.01)
        pressure = correction_ratio * sdp810_125.get_reading()
    except BaseException as error: # covers all errors
        print("error, probably comm error with pressure sensor:", error)
        read_fail_strikes += 1
        if read_fail_strikes > 5: #if it fails to read more than 5 times in a row
            sleep(10)#reset the whole system by triggering watchdog
        return oldpressure
    oldpressure = pressure
    read_fail_strikes = 0
    return pressure
def try_connect_forever():
    global ip
    ip = None
    while ip == None:#keep trying forever
        wdt.feed()
        ip, wlan = connect_wifi(ssid_main_wifi,password_main_wifi)
    return ip, wlan
mqtt_cfm = 50
last_b = mqtt_cfm
last_a = check_pot()
perc = 50
def combine_percs(a, b):
    global last_b
    global last_a
    global perc
    if abs(last_b - b)>1:
        perc = b
        last_b = b
    if abs(last_a - a)>1:
        perc = a
        last_a = a
    return perc
def cb(topic, msg):# this only gets executed if there is an mqtt message recieved, it's the callback
    global mqtt_perc
    try:
        perc = int(str(msg)[2:-1]) #should be a bytes object, so if we convert it to a string chop off extras then int that should work.
    except BaseException as error:
        print("there was no message or it was not a valid integer, message was:",str(msg)[2:-1],"error was: ",)
    else:
        mqtt_perc = perc
        print("mqtt perc command recieved mqtt_perc variable updated:", mqtt_perc)
mqtt_feedname_publish = 0 
def connect_mqtt():
    global ADAFRUIT_USERNAME
    global ADAFRUIT_IO_FEEDNAME
    global ADAFRUIT_IO_FEEDNAME_publish
    global ADAFRUIT_IO_URL
    global ADAFRUIT_IO_KEY
    global mqtt_feedname_publish
    mqtt_feedname = bytes('{:s}/feeds/{:s}'.format(ADAFRUIT_USERNAME, ADAFRUIT_IO_FEEDNAME), 'utf-8')
    mqtt_feedname_publish = bytes('{:s}/feeds/{:s}'.format(ADAFRUIT_USERNAME, ADAFRUIT_IO_FEEDNAME_publish), 'utf-8')
    random_num = int.from_bytes(os.urandom(3), 'little')
    mqtt_client_id = bytes('client_'+str(random_num), 'utf-8')
    client = MQTTClient(client_id=mqtt_client_id, 
                        server=ADAFRUIT_IO_URL, 
                        user=ADAFRUIT_USERNAME, 
                        password=ADAFRUIT_IO_KEY,
                        ssl=False)
    client.set_callback(cb)
    try:
        print("about to start mqtt connection")
        wdt.feed()
        client.connect()
        wdt.feed()
        mqtt_connected = 1
        print("mqtt connected ok! Recieve feed name:", ADAFRUIT_IO_FEEDNAME, "Status updates feedname:",ADAFRUIT_IO_FEEDNAME_publish)
    except Exception as e:
        mqtt_connected = 0
        print('could not connect to MQTT server, oserror -1 means the adafruit server is not working right or key or username not right -2 usually means no internet connection: {}{}'.format(type(e).__name__, e))
        print("username: ",ADAFRUIT_USERNAME, " key: ",ADAFRUIT_IO_KEY)
    if mqtt_connected == 1:
        wdt.feed()
        client.subscribe(mqtt_feedname)
        wdt.feed()
    return mqtt_connected, client
def comm_mqtt(mqtt_connected):
    if mqtt_connected == 1:
        try:
            print("got this far6")
            sleep(0.1)
            mqtt_publish(ticks_ms())
            print("clock time published")
            sleep(0.1)
            client.check_msg() #if changed from follower to leader this will cause an error, just let it go and let the watchdog reboot.
            print("mqtt messages checked ok")
        except BaseException as error:
            print("apparently connected to mqtt but got an error during effort to communicate over mqtt", error)
    return
def send_synch_udp():
    global main_perc
    global ip_follower
    receiver_port = 12345
    sock = socket.socket(socket.AF_INET, socket.SOCK_DGRAM)
    x = 0
    try:
        while x < 3 :
            # Send "Hello, world!" message
            reply = str(ticks_ms())+","+ str(main_perc)
            sock.sendto(reply.encode(), (ip_follower, receiver_port))
            print(f"Sent: {reply}")
            wdt.feed()
            sleep(1)
            x = x + 1
    except BaseException as error:
        print("error while sending udp synch packet:", error)
    finally:
        sock.close()
def listen_udp_follower():
    listen_port = 12345

    data = None
    timer = ticks_ms()
    big_timeout = 100
    wdt.feed()
    while data == None and ticks_diff(ticks_ms(),timer) < (big_timeout*1000):
        try:
            sock = socket.socket(socket.AF_INET, socket.SOCK_DGRAM)
            sock.bind(('', listen_port))
            print(f"Listening for UDP messages on port {listen_port}")
            sock.settimeout(3)#timeout in seconds
            wdt.feed()
            data, addr = sock.recvfrom(1024)
            wdt.feed()
            print(f"Received '{data.decode()}' from {addr}")
            return data.decode()
        except BaseException as error:
            wdt.feed()
            print("error while listening for udp synch packet:", error)
            sleep(1)
            wdt.feed()
        finally:
            sock.close()
    return None
def follower_wait_synch():
    global main_perc
    status = "not synched"
    message = None
    message = listen_udp_follower()
    wdt.feed()
    print("listened for a while, no synch packet recieved")
    print("message (synch packet presumably) recieved:", message)
    if message == None:
        reset()
        return status
    if len(message) > 4: # basic check we got a valid message
        recieved_items = message.split(",") #split the message so we can get different fields of different length reliably
        clock_leader = int(recieved_items[0])
        main_perc = float(recieved_items[1])
        update_clock(clock_leader)
        print("local clock on follower updated:",ticks_ms2())
        print("main power level from leader recieved and updated on follower:",main_perc) 
        status = "synched"
    return status
def check_wifi_reconnect(ip, wlan):
    try:    
        if wlan.isconnected() == False and leader_or_follower == "leader":
            wdt.feed()
            ip, wlan = try_connect_forever() 
            return ip, wlan
    except BaseException as error:
            print("error trying to reconnect wifi, probbly it means we are in ap mode if wlan doesn't exist error is:", error)
            return ip_leader, "none"
    return ip, wlan  
last_ingress_throttle = 0
last_egress_throttle = 0
mqtt_perc = check_pot()
main_perc = check_pot()
#sys.exit()# this is useful for testing.  it causes things to return to the repl so you can run functions etc. as desired, ctrl+c will also do that unless you are in a try except block.
wdt = WDT(timeout = 6500)
led=machine.Pin('LED', machine.Pin.OUT)
globals().update(persistent_vars_dict)
root_files = os.listdir('/')
if 'persistent_vars.json' not in root_files: # if the file doesn't exist then create it with the defaults.
    save_vars()
restore_vars()
ip = None
wdt.feed()
ip, wlan = try_connect_forever()
mqtt_connected = 0

wdt.feed()
try:    
    if wlan.isconnected() == True and leader_or_follower == "leader":
        try:
            wdt.feed()
            uping.ping(ip_follower)
            wdt.feed()
            uping.ping('192.168.4.1')# if it's connected to the access point this should be the ip of the leader *it also is necessary to add this ip to the router table so things work
            wdt.feed()
            uping.ping(ADAFRUIT_IO_URL)#just to verify we can connect, makes troubleshooting easier.
            wdt.feed()
            mqtt_connected, client = connect_mqtt()
            wdt.feed()
        except BaseException as error:
            print("error trying to ping stuff to test wifi and then connect mqtt etc.  -2 seems to be no internet connection: ",error)
    if wlan.isconnected() == True and leader_or_follower == "follower":
        wdt.feed()
        uping.ping('192.168.4.1')# if it's connected to the access point this should be the ip of the leader *it also is necessary to add this ip to the router table so things work
        wdt.feed()
except BaseException as error:
        print("error trying to ping stuff:", error)
while True:
    wdt.feed()
    combi_fan_spd(last_ingress_throttle,last_egress_throttle)
    if leader_or_follower == "leader":
        cp_ingress = check_cp_ingress()
        if mqtt_connected == 1:
            wdt.feed()
            comm_mqtt(mqtt_connected)
            wdt.feed()
        main_perc = combine_percs(check_pot(), mqtt_perc)
        ip, wlan = check_wifi_reconnect(ip, wlan)
        send_synch_udp()
    if leader_or_follower == "follower":
        status = "not synched"
        while status != "synched":
            ip, wlan = check_wifi_reconnect(ip, wlan)
            wdt.feed()
            status = follower_wait_synch()
            wdt.feed()
            print("synch status from most recent try: ", status)
        cp_ingress = check_cp_ingress()*(-1)
    period_time = period_time_calc()
    pid_ingress.setpoint = cp_ingress
    pid_ingress.set_auto_mode(True, last_output=last_ingress_throttle)
    while (ticks_ms2()%period_time) < period_time/2: #if ingress section run ingress pid     
        for i in range(100):
            last_ingress_throttle = run_pid_ingress()
            wdt.feed()
        if leader_or_follower == "leader":
            main_perc = combine_percs(check_pot(), mqtt_perc)
            cp_ingress = check_cp_ingress()
        pid_ingress.setpoint = cp_ingress
        p, i, d = pid_ingress.components
        print(" sp:", pid_ingress.setpoint, " p:",check_actual_pressure()," throttle:", last_ingress_throttle) #," timemodulo:", ticks_ms()%period_time)
    pid_ingress.set_auto_mode(False)
    combi_fan_spd(last_egress_throttle, last_ingress_throttle)
    if leader_or_follower == "leader":
        cp_egress = check_cp_egress()
        main_perc = check_pot()
    if leader_or_follower == "follower":
        cp_egress = check_cp_egress()*(-1)
    pid_egress.setpoint = cp_egress
    pid_egress.set_auto_mode(True, last_output=last_egress_throttle)
    while period_time/2 < (ticks_ms2()%period_time) : #egress time
        for i in range(100):
            last_egress_throttle = run_pid_egress()
            wdt.feed()
        if leader_or_follower == "leader":
            main_perc = combine_percs(check_pot(),mqtt_perc)
            cp_egress = check_cp_egress()
        pid_egress.setpoint = cp_egress
        p, i, d = pid_egress.components
        print(" sp:", pid_egress.setpoint, " p:",check_actual_pressure()," throttle:", last_egress_throttle)#, " timemodulo:", ticks_ms()%period_time )
    pid_egress.set_auto_mode(False)

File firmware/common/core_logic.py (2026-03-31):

# Licensed under CC BY-NC-SA 4.0
# Core Logic: Reliability & Safety Improvements

import json
import time
import os
import network
import socket
import select
from machine import Pin, ADC, WDT, I2C, reset
from simple_pid import PID
from umqtt.robust import MQTTClient
import uping

from sdp810 import SDP810
from network_manager import NetworkManager
from fan_manager import FanManager
from provisioning import ProvisioningManager

class OpenERVCore:
    # Engineering Constants
    THERMAL_LIMIT_C = 50.0  # Safe threshold below MPLA softening point (55C)
    # Using shift-based EMA: filtered = (raw + (filtered * (2^N - 1))) >> N
    # This is efficient on small MCUs
    ADC_FILTER_SHIFT = 3    # N=3 -> approx 0.125 alpha

    def __init__(self, model_config):
        self.config = {
            "ssid_main_wifi": "use_ap",
            "password_main_wifi": "none",
            "ssid_ap": "OpenERV_AP",
            "ap_password": "osrocks8882888",
            "ip_leader": '192.168.4.1',
            "ip_follower": '192.168.4.2',
            "leader_or_follower": "leader",
            "ADAFRUIT_USERNAME": b'',
            "ADAFRUIT_IO_KEY": b'',
            "ADAFRUIT_IO_FEEDNAME": b'OpenERV_Default',
            "ADAFRUIT_IO_FEEDNAME_publish": b'OpenERV_Default_status',
            "P_gain": 0.15,
            "I_gain": 0.35,
            "max_pressure": 30,
            "pressure_ratioa": 1.0,
            "pressure_ratiob": 1.0,
        }
        self.config.update(model_config)
        
        self.led = Pin("LED", Pin.OUT)
        self.wdt = WDT(timeout=8000)
        
        # Initialize components
        self.net = NetworkManager(wdt=self.wdt, led=self.led)
        self.i2c = I2C(1, scl=Pin(19), sda=Pin(18), freq=100000)
        self.sensor = SDP810(self.i2c)
        self.fans = FanManager()
        self.prov = ProvisioningManager(self.net)
        
        self.pid_ingress = PID(self.config['P_gain'], self.config['I_gain'], 0, setpoint=15)
        self.pid_ingress.output_limits = (-100, 100)
        self.pid_egress = PID(self.config['P_gain'], self.config['I_gain'], 0, setpoint=15)
        self.pid_egress.output_limits = (-100, 100)
        
        self.pot = ADC(Pin(28))
        self.filtered_pot_raw = 0  # Store as integer for bit-shifting
        self.mqtt_perc = 40
        self.main_perc = 50
        self.client = None
        self.mqtt_connected = 0
        self.mqtt_feedname_publish = None
        
        self.last_ingress_throttle = 0
        self.last_egress_throttle = 0
        self.delta_from_internal_clock = 0
        self.read_fail_strikes = 0
        self.oldpressure = 0
        self.current_temp = 0.0
        self.thermal_shutdown_active = False

    def load_persistent_vars(self):
        filename = "persistent_vars.json"
        try:
            with open(filename, "r") as f:
                self.config.update(json.load(f))
            print("Loaded persistent_vars.json")
            return True
        except Exception:
            print("No persistent_vars.json found.")
            return False

    def handle_safety_checks(self):
        """Global safety state machine. Run this every loop iteration."""
        # 1. Thermal Safety
        if self.current_temp > self.THERMAL_LIMIT_C:
            if not self.thermal_shutdown_active:
                print(f"CRITICAL: THERMAL LIMIT EXCEEDED ({self.current_temp}C). EMERGENCY SHUTDOWN.")
                self.fans.update(0, 0)
                self.thermal_shutdown_active = True
                self.led.on()
            return False
        
        self.thermal_shutdown_active = False
        return True

    def get_conditioned_adc(self):
        """Integer-based EMA filter with 8-sample accumulation."""
        raw = self.pot.read_u16()
        # Scale up the input to match the 8-sample accumulator
        # filtered = (new_scaled + (old_accum * 7)) / 8
        self.filtered_pot_raw = (raw + (self.filtered_pot_raw * 7)) >> 3
        return self.filtered_pot_raw / 655.35 # Normalized 0-100

    def check_actual_pressure(self):
        correction_ratio = 3.45
        try:
            time.sleep(0.01)
            pressure_raw, temp_raw = self.sensor.get_reading()
            if pressure_raw is None:
                self.read_fail_strikes += 1
                if self.read_fail_strikes > 10: reset()
                return self.oldpressure
            
            self.current_temp = temp_raw
            self.oldpressure = correction_ratio * pressure_raw
            self.read_fail_strikes = 0
            return self.oldpressure
        except Exception as e:
            print(f"I2C Read Error: {e}")
            self.read_fail_strikes += 1
            return self.oldpressure

    def percent_to_pressure(self, perc):
        max_p = self.config['max_pressure']
        pressure = perc * max_p / 100
        pressure = max(-max_p, min(max_p, pressure))
        if -4 < pressure < 4:
            pressure = 0
        return pressure

    def check_cp_ingress(self):
        if self.main_perc < 40:
            return self.percent_to_pressure(self.main_perc) * self.config['pressure_ratiob']
        return self.percent_to_pressure(self.main_perc) * self.config['pressure_ratioa']

    def check_cp_egress(self):
        if self.main_perc < 40:
            return -1 * self.percent_to_pressure(self.main_perc) / self.config['pressure_ratiob']
        return -1 * self.percent_to_pressure(self.main_perc) / self.config['pressure_ratioa']

    def mqtt_callback(self, topic, msg):
        try:
            self.mqtt_perc = int(msg.decode())
            print(f"MQTT command: {self.mqtt_perc}")
        except: pass

    def connect_mqtt(self):
        if not self.config['ADAFRUIT_USERNAME'] or not self.config['ADAFRUIT_IO_KEY']:
            return 0, None
        mqtt_feedname = bytes('{:s}/feeds/{:s}'.format(self.config['ADAFRUIT_USERNAME'].decode(), self.config['ADAFRUIT_IO_FEEDNAME'].decode()), 'utf-8')
        self.mqtt_feedname_publish = bytes('{:s}/feeds/{:s}'.format(self.config['ADAFRUIT_USERNAME'].decode(), self.config['ADAFRUIT_IO_FEEDNAME_publish'].decode()), 'utf-8')
        client_id = bytes('client_' + str(int.from_bytes(os.urandom(3), 'little')), 'utf-8')
        client = MQTTClient(client_id=client_id, server=self.config['ADAFRUIT_IO_URL'], user=self.config['ADAFRUIT_USERNAME'], password=self.config['ADAFRUIT_IO_KEY'], ssl=False)
        client.set_callback(self.mqtt_callback)
        try:
            self.wdt.feed()
            client.connect()
            client.subscribe(mqtt_feedname)
            print("MQTT Connected")
            return 1, client
        except:
            return 0, None

    def period_time_calc(self):
        power = max(0.1, self.main_perc)
        return min(120000, 50000 / (power / 100))

    def ticks_ms_synced(self):
        if self.config['leader_or_follower'] == "leader":
            return time.ticks_ms()
        return time.ticks_diff(time.ticks_ms(), self.delta_from_internal_clock)
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

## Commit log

2025-12-15 initial upload
    [2-20blades 22 degress 40 mm hub dia straightener.stl, clamptry2.stl, combi hood.stl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]
2026-03-30 Reorganize repository structure, convert docs to Markdown, and add CC BY-NC-SA 4.0 license
    [2-20blades 22 degress 40 mm hub dia straightener.stl, 22deg 55mm hub flow straightneer worked best as of nov 23 2024.f3z, clamptry2.stl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]
2026-03-31 Improve schematic distribution by adding EasyEDA source files and documentation
2026-03-31 Reorganize design directory: consolidate common parts and standardize filenames
    [2-20blades 22 degress 40 mm hub dia straightener.stl, clamp_v2.stl, clamptry2.stl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]
2026-03-31 Implement technical audit fixes: repair STL normals and standardize STEP filenames
    [interior_cover.stl, noise_splitter.step, outdoor_cover.stl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]
2026-03-31 Add standardized Open BOM files for TW4 and WM12
    [BOM_TW4.csv, BOM_WM12.csv]
2026-03-31 Add standardized 3D printing specifications (print_specs.json) and document manufacturing requirements
2026-03-31 Resolve printing ambiguities: add part orientations, support guidance, and slicer calibration documentation
2026-03-31 Implement automated STL manufacturing analysis using PrusaSlicer CLI
    [MANUFACTURING_REPORT.csv]
2026-03-31 Integrate useful historical assets into research/ and purge redundant archives
    [flow_straightener_v1_22deg.f3z, noise_splitter_v29_experimental.f3z]
2026-03-31 Engineering Hardening: thermal safety cutoff, EMA ADC filtering, and wiring/timing diagrams
2026-03-31 Logic Refactor: Clean up side-effects, implement integer-based ADC filtering, and fix workflows
    [core_logic.py]
2026-03-31 CI Upgrade: Move to current 2026 GitHub Actions and upstream ARM GCC
2026-03-31 Fix: Update MicroPython target board name from PICO_W to RPI_PICO_W
2026-03-31 Fix: Explicitly pass BOARD to submodule initialization to ensure WiFi drivers are fetched
2026-03-31 Build Optimization: Implement job-level path filtering and multi-layer caching for mpy-cross and submodules
2026-03-31 Automation: Enhance release workflow with manual trigger and inclusion of manufacturing assets (BOM/Report)
2026-03-31 Tone: Replace overly grandiose language with neutral professional terminology
    [core_logic.py]
2026-03-31 Tone: Systematically remove unquantifiable adjectives and replace with objective technical terms
    [core_logic.py]

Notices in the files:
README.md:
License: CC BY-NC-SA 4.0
